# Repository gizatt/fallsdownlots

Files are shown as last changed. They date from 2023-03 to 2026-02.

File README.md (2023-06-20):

# FallsDownLots

<details>
  <summary>Click to expand more demo GIFs</summary>
  
  
  
</details>

## About
This project ("FallsDownLots") is a 2-wheeled balancing robot designed around two brushless DC (BLDC) gimbal motors, controlled with field-oriented control. Previous iterations of wheeled balancing robots I've built have been plagued by issues with poor motor control (primarily backlash, inertia, and friction causing shaky control around the upright fixed point). This project instead uses a high-torque (specifically low KV / high winding count) 3-phase motor, paired with an absolute magnetic encoder to determine the shaft angle, and a 3-phase drive circuit to deliver current. With some pretty simple parts, I've been able to get something pretty close to actual torque control for the wheels of this robot, and it's been pretty easy to tune up for smooth, stable, remote-controllable operation.

For ease of control tuning, I chose a main board with Bluetooth Low-Energy (BLE) support, and written a companion program that connects to the robot and allows parameter updates. This program is currently very primitive but it beats reprogramming or having it drag around a serial cable (which interferes with control).

I mostly rely on [SimpleFOC](https://simplefoc.com/) for the actual FOC implementation, and took their advice on sensor and drive chip choice. I'd like to dive deeper into controlling these motors better -- for example, trying to compensate for cogging torque to get smoother operation - but I have more fundamental issues to fix first (see below).

- For code, see the `fallsdownlots` subdirectory (which is a PlatformIO package).
- For CAD, see [Onshape](https://cad.onshape.com/documents/34e0d9ef519aef4b34c19df6/w/b4fc20d7f51a03280199ecb2/e/801a65f226a9bb9fc692247b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). Sorry it's not organized into a main assembly yet, this is just my 3D print part workshop. Approximately up-to-date STLS are in the `stls` subdirectory. Print `MotorMount` twice, mirroring one of them. Print `Wheel` twice. Print `Tire` twice in TPU or another tacky, flexible filament.
- For PCB design and electrical schematics, see `board_v2` subdirectory (which is a KiCad project).

## Diagram and Parts List
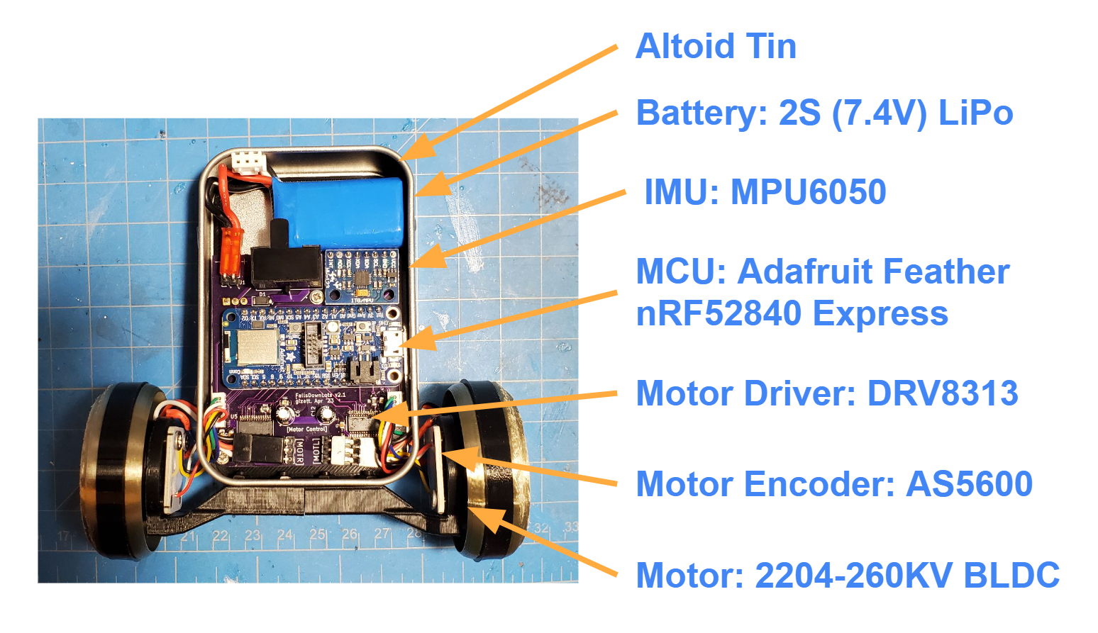
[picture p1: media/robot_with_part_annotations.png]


(Note: this references a special-edition physically packaged version of this robot.)

Parts list:
- 2X PLA wheel with TPU tire
- 2x Motor assembly, composed of...
  - 1x PLA Wheel + TPU tire
  - 1x PLA Motor Mount
  - 1x AS5600 Breakout Board
  - 1X 2204-260KV BLDC Motor (with 3-pin JST RE connector)
  - 1X 10KOhm Thermistor
  - 1X JST MX 6-pin Male Connector
- 1x Altoid tin case with lid, containing...
  - 1x PLA board mounting backplate, already attached to case.
  - 1x Main electronics board
  - 4x M3x8mm hex bolts and nuts
  - 8x M2x4mm hex bolts
  - 3x M2x8mm self-tapping phillips screws
  - Spare parts: M3x8mm self-tapping phillips screws, plus other screw types, plus spare TPU tire

Not included (supply seperately):
- 1x 400Mah 2S LiPO [[Amazon link](https://www.amazon.com/gp/product/B072BH1XP6/ref=ox_sc_act_title_1?smid=A10R5CWYCW5T5E&psc=1)] and balance charger.
- 1.5 and 2.5 metric alley keys
- Small phillips head screwdriver
- Small narrow / needle-nose pliers
- Non-ancient bluetooth adapter (probably needs BLE >= 5.1?)

## Assembly Instructions

Assembly is simple, but the tight packaging makes assembly pretty order-sensitive.

1) Attach the motor assemblies onto the bottom of the case, as shown, using 4x M3x8mm hex bolts and nuts. Before you fully attach these, pass their wires into the case through the nearby holes; otherwise it'll be a tight fit to get those wires passed in, especially with the electronics board mounted. Be reasonably gentle with the wires...


2) Now install the main electronics board by sliding it into place and installing the 3x M2x8mm self-tapping phillips screws, which screw into posts on the PLA backplate. Note that you want the wires from the motor assemblies *over* the main board once it's installed -- it's a bit of dance to get it everything into place.
3) Plug in the wires from the motor assemblies into the plugs on their corresponding side. See picture for exact orientation of wires -- carefully note the orientation of the 3-pin motor connectors! If you get this backwards, the motors will spin the wrong way. I recommend some good needlenose pliers to help with wrangling and attaching these cables.
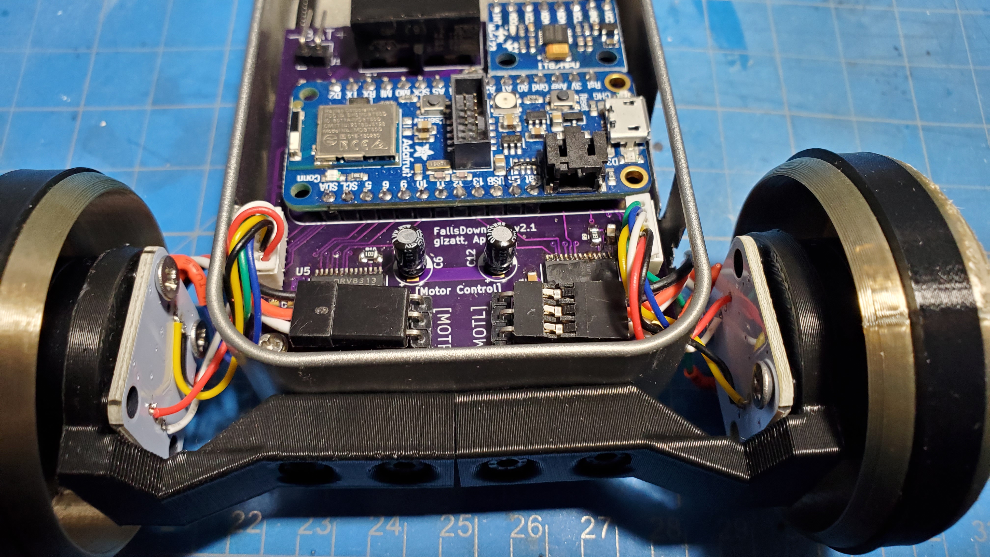
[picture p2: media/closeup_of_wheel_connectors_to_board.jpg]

4) Attach the tires to the motors with at least 2x M2x4mm hex bolts each. These bolts should be snug but don't go ham (the PLA may not be able to take it).
5) Slide the battery into the space under the on-off switch with the cables facing left, and plug in the cable, being careful to have the red wire on the right. *This board technically has reverse bias protection but I have never tested it and I do not want you to either.*

Troubleshooting: contact me!

### Motor assembly internals

I packaged this robot with each motor and sensor already assembled, since their assembly is a bit sensitive, but you're welcome to disassemble and take a look. These assemblies are pancakes of a tiny BLDC motor ([Amazon link](https://www.amazon.com/DAUERHAFT-Brushless-Efficiency-Drones-Gimbal/dp/B08S5JSD3Q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), though this unit is much cheaper on Aliexpress) with a magnet superglued to its shaft, an [absolute magnetic encoder](https://www.amazon.com/Magnetic-Encoder-Induction-Measurement-Precision/dp/B094F8H591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) on a breakout board, and a thermistor sandwiched between them.



## Usage instructions

Flip the switch to the right to turn on. I recommend laying the robot down or standing it on its head during startup; each wheel will independent move a quarter rotation back and forth during startup as a calibration routine (this is managed by SimpleFOC). Once that is done, the robot should be active, and will attempt to balance to the upright if it is within ~60 degrees of upright. The easiest way to get it going is to go to a clear area of floor, holding it sideways, and confidentally and quickly place it roughly upright and let go. The integrators reset and motors turn off again when it is not upright, e.g. if it falls.

I recently discovered another fun demo method that happens to work, despite the control algorithm not being created with this in mind: hold the robot by the wheels, and swing the robot upright. It should catch itself at the upright and stabilize there. See [this video](media/flipup_demo.gif).

Note: there's a few bugs somewhere in the code, especially in the BLE stuff, and sometimes the IMU or magnetic encoders get into weird states and stop talking. If the robot suddenly stops and falls over, or otherwise seems unresponsive, just do a complete power cycle. This is more likely to happen if you're using one of the BLE scripts, proportional to how much data you're sending/receiving.

## Control details

The main control code is implemented in `main-fallsdownlots.cpp::do_control`. I'm currently running a PID loop on angle, with the zero angle estimated via a low-pass filter on the measured angle (which assumes we stabilize on average to the upright), plus a PI loop on wheel velocity, plus a PI loop on yaw velocity. These are all controlled by parameters in the `ControlParams` struct.

There are two Python scripts in the `fallsdownlots/scripts` folder. Both connect to the robot with BLE.
- `communicator.py`: Once connected, type a command of the format "<param name> <float value>" and hit enter, and it'll send it to the robot. It should echo the new setting back, though sometimes it takes a while to come back. If you just send "<param name>" without a value, it'll send the current value back. Example: "ANG_D 0.1" changes the derivative gain to 0.1. Ignore the plot window that opens up, it doesn't work yet...
- `gamepad.py`: Connects to the robot and sends commands (adjusting the setpoints of the velocity and yaw velocity control loops) in response to the arrow keys, letting you control the robot. Hold shift while pressing arrow keys to go faster. There's a mode to display robot odometry (see code) but it's currently super sketchy.

## Notes / Thoughts

### TODOs
- Major code cleanup. Tons of cruft left here I haven't re-orged.
- Use BLE interface to create an interactive motor teststand for tuning up actual motor control loops.

### Stuff that didn't work as well as I hoped
- Because I'm talking to 2 magnetic encoders and 1 IMU over relatively slow I2C (800khz, I think), I haven't been able to get my main control loop to run faster than ~200hz. I'm configuring the IMU to do its own high-rate on-board orientation estimation, so that's fine -- but this low rate makes it hard to drive the motors in anything other than torque mode (velocity and position mode go unstable pretty easily / can't be tuned to be too accurate as my loop rate is probably too low), and I can't crank the actual control gains as high as I'd like for tight tracking without inducing oscillations. It's possible I can get info from at least the magnetic encoders over their analog output instead... but I would need to experiment with that.
- I'm relying on Bluetooth Low-Energy as my wireless comms media, but I'm finding the bandwidth super low, and the code on the embedded side super crash-prone. I'm probably overloading buffers somewhere and configuring stuff wrong... next time, I'm just gonna have the robot connect to my Wifi. I'd rather deal with networking gremlins I sort of understand than BLE ones I don't.

### BLE Comms Protocol

The robot sends a 36-byte (+COBS-encoding) packet over BLE UART at ~30hz consisting of 8 floats:
```
[pitch, yaw, d_pitch, d_yaw, odometry, l_cmd, r_cmd, max_motor_temp]
```

On-board, the robot has a registry of named control parameters that you can write with a command formatted:
```
<NULL-TERMINATED-NAME>[optional single float]
```
and the robot will respond with a similarly formatted message (+COBS-encoding) packet with a single float indicating the updated value, or the current value if you didn't include the float value.

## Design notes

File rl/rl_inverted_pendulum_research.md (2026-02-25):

# RL Controller for Two-Wheeled Inverted Pendulum: Research & Implementation Plan

**Robot:** Altoids tin chassis, two BLDC outrunners, SimpleFOC, magnetic encoder, Arduino Nano 33 BLE (nRF52840), onboard IMU.
**Goal:** Train an RL policy in MuJoCo simulation and deploy it to the Arduino.

---

## Table of Contents

1. [MuJoCo Ecosystem Overview](#1-mujoco-ecosystem-overview)
2. [Framework Comparison: Standalone vs mjlab](#2-framework-comparison-standalone-vs-mjlab)
3. [Recommended Project Structure (Standalone)](#3-recommended-project-structure-standalone)
4. [mjlab-Based Project Structure](#4-mjlab-based-project-structure)
5. [Phase 1: MuJoCo Environment](#5-phase-1-mujoco-environment)
6. [Phase 2: RL Algorithm Choice](#6-phase-2-rl-algorithm-choice)
7. [Phase 3: Training Infrastructure](#7-phase-3-training-infrastructure)
8. [Phase 4: Domain Randomization](#8-phase-4-domain-randomization)
9. [Phase 5: Deploying to Arduino Nano 33 BLE](#9-phase-5-deploying-to-arduino-nano-33-ble)
10. [Implementation Sequence](#10-implementation-sequence)
11. [Sources](#11-sources)

---

## 1. MuJoCo Ecosystem Overview

### MuJoCo Ecosystem Map

| Package | Purpose | Backend | GPU? | Use When |
|---|---|---|---|---|
| `mujoco` | Standard Python bindings | CPU (C) | No | Quick prototyping, CPU-only |
| `mujoco-mjx` | JAX-accelerated MuJoCo | JAX (GPU/TPU) | Yes | Scaling to 1000s of envs (JAX) |
| `mujoco_playground` | Full RL framework on MJX | JAX | Yes | Full locomotion suite (JAX) |
| `mjlab` | Isaac Lab API on MuJoCo Warp | CUDA/Warp | Yes (NVIDIA) | Isaac Lab-style, NVIDIA GPU training |
| `mujoco-py` | Old OpenAI bindings | CPU | No | Deprecated — avoid |

`mjlab` ([github.com/mujocolab/mjlab](https://github.com/mujocolab/mjlab)) adopts Isaac Lab's manager-based composable API and pairs it with MuJoCo Warp (NVIDIA GPU physics). It is **directly analogous** to the Upkie wheeled biped project [mjlab_upkie](https://github.com/MarcDcls/mjlab_upkie), which trains a velocity-tracking and balancing policy for a wheeled biped robot — making it a very close reference for this project.

---

## 2. Framework Comparison: Standalone vs mjlab

### High-Level Tradeoffs

| Dimension | Standalone (`mujoco` + CleanRL) | mjlab |
|---|---|---|
| **GPU requirement** | None (CPU training works fine) | **NVIDIA GPU required** for training |
| **Parallelism** | 8–32 CPU envs (VectorEnv) | 256–4096+ GPU envs (MuJoCo Warp) |
| **Wall-clock training** | ~30–60 min (PPO, 8 envs, 3M steps) | ~5–15 min (2048 envs, same budget) |
| **Algorithm** | PPO, SAC, TD3 (full CleanRL library) | RSL-RL PPO (main); SAC not native |
| **Environment definition** | Python class (`gym.Env`), explicit `step()`/`reset()` | Declarative manager config (`env_cfg.py`), no explicit step |
| **Domain randomization** | Manual code in `_apply_domain_randomization()` | `EventManager` terms, declarative |
| **Logging** | TensorBoard (+ optional W&B) | W&B (primary), TensorBoard possible |
| **Learning curve** | Moderate — gymnasium + CleanRL are well-documented | Steeper — Isaac Lab paradigm (managers, `@configclass`) |
| **Stability** | Stable, mature dependencies | Beta — breaking changes expected |
| **Prior art for this robot** | Generic continuous-control examples | [mjlab_upkie](https://github.com/MarcDcls/mjlab_upkie): wheeled biped, nearly identical task |
| **Weight export to Arduino** | Straightforward (PyTorch → C arrays) | Same (RSL-RL actor is a PyTorch MLP) |

### When to Choose mjlab

Choose mjlab if:
- You have an **NVIDIA GPU** available for training
- You want **10–100x faster iteration** via massive parallelism (critical for domain randomization sweeps)
- You are willing to learn the Isaac Lab manager API (it scales well to more complex tasks)
- You want a ready-made reference: `mjlab_upkie` is almost exactly this project (wheeled biped, velocity control, sim-to-real)

Choose standalone if:
- You are training on **CPU only** (no NVIDIA GPU)
- You want the fastest possible **time-to-first-result** with minimal boilerplate
- You prefer SAC (better sample efficiency on CPU) — mjlab/RSL-RL is PPO-focused
- You want maximum flexibility over reward shaping and observation construction

### Decision Summary

> **If you have an NVIDIA GPU, mjlab is the stronger choice.** The mjlab_upkie reference implementation is a wheeled biped doing exactly what this project needs. Starting from it avoids writing a Gymnasium env from scratch and gets you to 2048 parallel environments immediately. The Isaac Lab config pattern is more verbose but scales better as the task complexity grows.
>
> **If training on CPU, use the standalone approach.** The gymnasium + CleanRL path is simpler, SAC is available, and 8 CPU envs is enough to train a basic balancer in under an hour.

---

## 3. Recommended Project Structure (Standalone)

```
rl/
├── envs/
│   ├── __init__.py              # gym.register() call
│   ├── two_wheel_env.py         # Gymnasium environment
│   └── two_wheel_robot.xml      # MJCF model
├── train_ppo.py                 # Single-file PPO training
├── train_sac.py                 # SAC alternative (copy from CleanRL)
├── export_weights.py            # PyTorch -> C array exporter
├── checkpoints/                 # Saved .pt checkpoints
├── runs/                        # TensorBoard logs
├── videos/                      # Periodic rendered episodes
└── firmware/
    ├── policy_weights.h         # Generated C weight arrays
    └── policy_inference.ino     # Arduino sketch
```

Install dependencies:
```bash
pip install "gymnasium[mujoco]" mujoco torch tensorboard cleanrl
```

---

## 4. mjlab-Based Project Structure

Based directly on [mjlab_upkie](https://github.com/MarcDcls/mjlab_upkie), adapted for a two-wheeled balancer.

```
rl/
├── src/
│   └── two_wheel_mjlab/
│       ├── __init__.py
│       ├── tasks/
│       │   └── balance_env_cfg.py       # Isaac Lab-style manager config
│       └── robot/
│           └── two_wheel/
│               └── two_wheel.xml        # MJCF model (same as standalone)
├── sim.py                               # CPU-side playback via mujoco.viewer
├── export_weights.py                    # RSL-RL checkpoint -> C array
├── pyproject.toml                       # uv/pip metadata
├── logs/                                # RSL-RL checkpoints + W&B artifacts
└── firmware/
    ├── policy_weights.h                 # Generated C weight arrays
    └── policy_inference.ino             # Arduino sketch (same as standalone)
```

Install:
```bash
pip install mjlab rsl-rl wandb
# or: uv add mjlab rsl-rl wandb
```

### 4.1 Environment Configuration (`tasks/balance_env_cfg.py`)

Rather than implementing `step()` and `reset()` by hand, mjlab uses a **declarative manager pattern** — you define *what* the observations, rewards, terminations, and randomization events are; the framework assembles the env loop:

```python
from dataclasses import dataclass, field
import mjlab
from mjlab import ManagerBasedRLEnvCfg, SceneEntityCfg
from mjlab.managers import ObservationsCfg, RewardsCfg, TerminationsCfg, EventCfg, CommandsCfg
import mjlab.managers.observation_terms as obs_terms
import mjlab.managers.reward_terms as rew_terms
import mjlab.managers.event_terms as evt_terms
import mjlab.managers.termination_terms as term_terms

@dataclass
class TwoWheelSceneCfg(SceneEntityCfg):
    num_envs: int = 2048
    dt: float = 0.002
    substeps: int = 5          # 10ms per policy step (100 Hz)
    robot_usd: str = "two_wheel/two_wheel.xml"

@dataclass
class TwoWheelObsCfg(ObservationsCfg):
    # These map to mjlab built-in terms or custom lambdas
    pitch:       obs_terms.ImuRpy      = field(default_factory=lambda: obs_terms.ImuRpy(indices=[1]))
    pitch_rate:  obs_terms.ImuGyro     = field(default_factory=lambda: obs_terms.ImuGyro(indices=[1]))
    roll:        obs_terms.ImuRpy      = field(default_factory=lambda: obs_terms.ImuRpy(indices=[0]))
    roll_rate:   obs_terms.ImuGyro     = field(default_factory=lambda: obs_terms.ImuGyro(indices=[0]))
    left_wheel:  obs_terms.JointVel    = field(default_factory=lambda: obs_terms.JointVel(joint="left_wheel_joint"))
    right_wheel: obs_terms.JointVel    = field(default_factory=lambda: obs_terms.JointVel(joint="right_wheel_joint"))
    base_vel:    obs_terms.BaseLinVel  = field(default_factory=obs_terms.BaseLinVel)
    yaw_rate:    obs_terms.BaseAngVel  = field(default_factory=lambda: obs_terms.BaseAngVel(indices=[2]))

@dataclass
class TwoWheelRewardsCfg(RewardsCfg):
    # Weighted reward terms; mjlab sums them each step
    upright:     rew_terms.UprightPitch     = field(default_factory=lambda: rew_terms.UprightPitch(weight=1.0))
    no_drift:    rew_terms.BaseLinVelPenalty = field(default_factory=lambda: rew_terms.BaseLinVelPenalty(weight=0.1))
    smooth_act:  rew_terms.ActionRatePenalty = field(default_factory=lambda: rew_terms.ActionRatePenalty(weight=0.05))
    no_tilt_vel: rew_terms.PitchRatePenalty  = field(default_factory=lambda: rew_terms.PitchRatePenalty(weight=0.1))

@dataclass
class TwoWheelTerminationsCfg(TerminationsCfg):
    fallen: term_terms.BadOrientation = field(
        default_factory=lambda: term_terms.BadOrientation(limit_pitch=0.5)  # ~28 deg
    )
    timeout: term_terms.TimeOut = field(default_factory=lambda: term_terms.TimeOut(max_episode_steps=1000))

@dataclass
class TwoWheelEventCfg(EventCfg):
    """Domain randomization applied at reset."""
    rand_friction:  evt_terms.RandomizeFriction    = field(default_factory=lambda: evt_terms.RandomizeFriction(scale=(0.6, 1.4)))
    rand_mass:      evt_terms.RandomizeMass        = field(default_factory=lambda: evt_terms.RandomizeMass(scale=(0.8, 1.2)))
    rand_damping:   evt_terms.RandomizeDamping     = field(default_factory=lambda: evt_terms.RandomizeDamping(scale=(0.7, 1.3)))
    rand_motor:     evt_terms.RandomizeActuatorGain = field(default_factory=lambda: evt_terms.RandomizeActuatorGain(scale=(0.8, 1.2)))
    init_tilt:      evt_terms.RandomizeInitPitch   = field(default_factory=lambda: evt_terms.RandomizeInitPitch(range=(-0.08, 0.08)))

@dataclass
class TwoWheelBalanceCfg(ManagerBasedRLEnvCfg):
    scene:        TwoWheelSceneCfg       = field(default_factory=TwoWheelSceneCfg)
    observations: TwoWheelObsCfg         = field(default_factory=TwoWheelObsCfg)
    rewards:      TwoWheelRewardsCfg     = field(default_factory=TwoWheelRewardsCfg)
    terminations: TwoWheelTerminationsCfg = field(default_factory=TwoWheelTerminationsCfg)
    events:       TwoWheelEventCfg       = field(default_factory=TwoWheelEventCfg)
```

> **Note:** The exact manager term names (`obs_terms.ImuRpy`, `rew_terms.UprightPitch`, etc.) depend on mjlab's built-in library, which is still evolving. You may need to define custom terms as lambdas over MuJoCo data. The pattern is identical to Isaac Lab — see mjlab_upkie's `balance_env_cfg.py` for a concrete reference.

### 4.2 Register and Train

```python
# __init__.py
import mjlab
mjlab.register(
    id="TwoWheel-Balance-v0",
    entry_point=TwoWheelBalanceCfg,
)
```

```bash
# Train (NVIDIA GPU required):
uv run train TwoWheel-Balance-v0 --env.scene.num-envs 2048

# Play / evaluate on CPU:
python sim.py --checkpoint logs/rsl_rl/two_wheel_balance/bests/model.pt
```

Training uses **RSL-RL** (on-policy PPO) with automatic W&B logging.

### 4.3 CPU Fallback for Evaluation (`sim.py`)

mjlab_upkie ships a `sim.py` that runs the trained policy against a standard `mujoco.viewer` on CPU — identical to the standalone approach. The weight export and Arduino firmware are also identical since both produce a plain PyTorch MLP.

### 4.4 Key Differences Calling Out

| Topic | Standalone | mjlab |
|---|---|---|
| **Env loop** | Explicit Python (`step`, `reset`, `_get_obs`) | Implicit — framework assembles from manager terms |
| **Domain randomization** | Manual code in `_apply_domain_randomization()` | Declarative `EventCfg` terms at `reset` |
| **Reward shaping** | Python arithmetic in `_compute_reward()` | Weighted `RewardsCfg` terms summed by framework |
| **Observation noise** | Explicit numpy in `_get_obs()` | Noise added as an `ObservationNoiseCfg` term |
| **Scaling** | `num_envs=8` (CPU VectorEnv) | `num_envs=2048` (GPU, ~100x faster) |
| **Algorithm access** | Full CleanRL (PPO, SAC, TD3) | RSL-RL PPO (SAC not natively supported) |
| **Starting point** | From scratch | Fork [mjlab_upkie](https://github.com/MarcDcls/mjlab_upkie) |

### 4.5 mjlab Weight Export (Same as Standalone)

RSL-RL's actor is a standard `torch.nn.Sequential` MLP, so the export script from Section 9 (Option A) works without modification — just point it at the RSL-RL checkpoint instead of a CleanRL checkpoint.

---

## 5. Phase 1: MuJoCo Environment

### 3.1 MJCF Robot Model (`envs/two_wheel_robot.xml`)

```xml
<mujoco model="two_wheel_balancer">
  <compiler angle="radian"/>
  <option gravity="0 0 -9.81" timestep="0.002" integrator="RK4"/>

  <default>
    <joint damping="0.01" armature="0.01"/>
    <geom condim="3" friction="0.8 0.1 0.1"/>
  </default>

  <asset>
    <texture name="grid" type="2d" builtin="checker" rgb1=".1 .2 .3"
             rgb2=".2 .3 .4" width="300" height="300"/>
    <material name="grid" texture="grid" texrepeat="1 1" texuniform="true"/>
  </asset>

  <worldbody>
    <light pos="0 0 1.5" dir="0 0 -1" diffuse="1 1 1"/>
    <geom name="floor" size="0 0 .05" type="plane" material="grid" condim="3"/>

    <!-- Chassis: the "pendulum" body -->
    <body name="chassis" pos="0 0 0.065">
      <!-- freejoint allows unconstrained 3D motion -->
      <!-- For strict 2D: replace with slide(x) + slide(z) + hinge(pitch-Y) -->
      <freejoint name="chassis_free"/>
      <!-- ~80g representing altoids tin + battery + electronics -->
      <geom name="chassis_box" type="box" size="0.03 0.025 0.05"
            mass="0.08" rgba="0.6 0.3 0.1 1"/>
      <site name="imu_site" pos="0 0 0" size="0.005"/>

      <body name="left_wheel" pos="0 -0.04 -0.05">
        <!-- Hinge spins around Y axis -->
        <joint name="left_wheel_joint" type="hinge" axis="0 1 0" damping="0.005"/>
        <geom type="cylinder" size="0.035 0.008" mass="0.02"
              rgba="0.2 0.2 0.8 1" friction="1.0 0.1 0.1"/>
      </body>

      <body name="right_wheel" pos="0 0.04 -0.05">
        <joint name="right_wheel_joint" type="hinge" axis="0 1 0" damping="0.005"/>
        <geom type="cylinder" size="0.035 0.008" mass="0.02"
              rgba="0.2 0.2 0.8 1" friction="1.0 0.1 0.1"/>
      </body>
    </body>
  </worldbody>

  <actuator>
    <!-- gear scales torque; tune to match measured SimpleFOC stall torque (~0.1-0.3 Nm) -->
    <motor name="left_motor"  joint="left_wheel_joint"
           ctrllimited="true" ctrlrange="-1.0 1.0" gear="1"/>
    <motor name="right_motor" joint="right_wheel_joint"
           ctrllimited="true" ctrlrange="-1.0 1.0" gear="1"/>
  </actuator>

  <sensor>
    <gyro      name="imu_gyro"       site="imu_site" noise="0.01"/>
    <framequat name="chassis_quat"   objtype="body" objname="chassis"/>
    <jointvel  name="left_wheel_vel" joint="left_wheel_joint"/>
    <jointvel  name="right_wheel_vel" joint="right_wheel_joint"/>
  </sensor>
</mujoco>
```

**Key modeling decisions:**
- `freejoint` gives full 6-DOF chassis motion (pitch, roll, yaw, xyz translation). This matches the real robot.
- `gear` on the motor actuator is the torque scaling constant. Tune this by measuring max torque output from SimpleFOC.
- Wheel `friction="1.0 0.1 0.1"`: first value is sliding friction (dominant for rolling), second torsional, third rolling resistance.

### 3.2 Gymnasium Environment (`envs/two_wheel_env.py`)

```python
"""
Gymnasium-compatible two-wheeled balancing robot environment.
Wraps MuJoCo via the standard `mujoco` Python bindings.
"""
import os
import numpy as np
import mujoco
import gymnasium as gym
from gymnasium import spaces

class TwoWheelBalancerEnv(gym.Env):
    """
    Observation space (9-dim):
        [0] chassis pitch angle (rad)
        [1] chassis pitch rate (rad/s)
        [2] chassis roll angle (rad)
        [3] chassis roll rate (rad/s)
        [4] left wheel velocity (rad/s)
        [5] right wheel velocity (rad/s)
        [6] x velocity (m/s)
        [7] y velocity (m/s)
        [8] yaw rate (rad/s)

    Action space (2-dim):
        [0] left motor torque  in [-1, 1]
        [1] right motor torque in [-1, 1]
    """

    metadata = {"render_modes": ["human", "rgb_array"], "render_fps": 50}

    def __init__(self, render_mode=None, xml_path=None, domain_randomize=True):
        super().__init__()

        if xml_path is None:
            xml_path = os.path.join(os.path.dirname(__file__), "two_wheel_robot.xml")

        self.model = mujoco.MjModel.from_xml_path(xml_path)
        self.data  = mujoco.MjData(self.model)
        self.domain_randomize = domain_randomize

        # Store nominal model parameters for domain randomization
        self._nominal_geom_friction  = self.model.geom_friction.copy()
        self._nominal_body_mass      = self.model.body_mass.copy()
        self._nominal_dof_damping    = self.model.dof_damping.copy()
        self._nominal_actuator_gear  = self.model.actuator_gear[:, 0].copy()

        self.dt           = self.model.opt.timestep  # 0.002 s
        self.frame_skip   = 5                         # -> 10ms per env step (100 Hz)
        self.max_episode_steps = 1000                 # 10 seconds

        obs_high = np.array([
            np.pi, 20.0, np.pi, 20.0,   # pitch, pitch_rate, roll, roll_rate
            50.0, 50.0,                  # wheel velocities
            3.0, 3.0, 10.0,             # x_vel, y_vel, yaw_rate
        ], dtype=np.float32)

        self.observation_space = spaces.Box(low=-obs_high, high=obs_high, dtype=np.float32)
        self.action_space = spaces.Box(low=-1.0, high=1.0, shape=(2,), dtype=np.float32)

        self._step_count = 0
        self._renderer = None
        self.render_mode = render_mode

    # ------------------------------------------------------------------
    # Gymnasium API
    # ------------------------------------------------------------------

    def reset(self, seed=None, options=None):
        super().reset(seed=seed)
        mujoco.mj_resetData(self.model, self.data)

        if self.domain_randomize:
            self._apply_domain_randomization()

        # Small random initial tilt: ±5 degrees
        pitch_init = self.np_random.uniform(-0.08, 0.08)
        # chassis_free joint: qpos[0:3]=xyz, qpos[3:7]=quaternion [w,x,y,z]
        half = pitch_init / 2.0
        self.data.qpos[3] = np.cos(half)  # w
        self.data.qpos[4] = 0.0            # x
        self.data.qpos[5] = np.sin(half)   # y (pitch axis)
        self.data.qpos[6] = 0.0            # z

        self._step_count = 0
        mujoco.mj_forward(self.model, self.data)
        return self._get_obs(), {}

    def step(self, action):
        action = np.clip(action, -1.0, 1.0).astype(np.float64)
        self.data.ctrl[:] = action

        for _ in range(self.frame_skip):
            mujoco.mj_step(self.model, self.data)

        obs = self._get_obs()
        reward = self._compute_reward(obs, action)

        pitch = obs[0]
        terminated = bool(abs(pitch) > 0.5)  # ~28 degrees -> fallen
        self._step_count += 1
        truncated = self._step_count >= self.max_episode_steps

        if self.render_mode == "human":
            self.render()

        return obs, reward, terminated, truncated, {}

    def render(self):
        if self._renderer is None:
            self._renderer = mujoco.Renderer(self.model, height=480, width=640)
        self._renderer.update_scene(self.data)
        if self.render_mode == "rgb_array":
            return self._renderer.render()

    def close(self):
        if self._renderer is not None:
            self._renderer.close()

    # ------------------------------------------------------------------
    # Internal helpers
    # ------------------------------------------------------------------

    def _get_obs(self):
        # chassis_free joint: qpos[0:3]=xyz, qpos[3:7]=quat(w,x,y,z)
        #                     qvel[0:3]=xyz_vel, qvel[3:6]=angular_vel
        quat = self.data.qpos[3:7]
        pitch, roll = _quat_to_pitch_roll(quat)

        pitch_rate = self.data.qvel[4]  # angular vel around Y (pitch axis)
        roll_rate  = self.data.qvel[3]  # angular vel around X (roll axis)
        yaw_rate   = self.data.qvel[5]  # angular vel around Z (yaw axis)
        x_vel      = self.data.qvel[0]
        y_vel      = self.data.qvel[1]

        # Wheel joints follow freejoint: qvel indices 6 and 7
        lw_vel = self.data.qvel[6]
        rw_vel = self.data.qvel[7]

        obs = np.array([
            pitch, pitch_rate, roll, roll_rate,
            lw_vel, rw_vel,
            x_vel, y_vel, yaw_rate,
        ], dtype=np.float32)

        # Add IMU-like sensor noise
        obs[0] += self.np_random.normal(0, 0.01)   # pitch noise  (~0.5 deg)
        obs[1] += self.np_random.normal(0, 0.05)   # pitch rate noise
        obs[2] += self.np_random.normal(0, 0.01)   # roll noise
        obs[3] += self.np_random.normal(0, 0.05)   # roll rate noise

        return obs

    def _compute_reward(self, obs, action):
        pitch, pitch_rate = obs[0], obs[1]
        x_vel, y_vel      = obs[6], obs[7]

        r_upright  =  1.0 - 2.0 * (pitch**2)       # reward for staying upright
        r_still    = -0.1 * (x_vel**2 + y_vel**2)  # penalize drifting
        r_smooth   = -0.05 * np.sum(action**2)       # penalize torque spikes
        r_tilt_vel = -0.1 * (pitch_rate**2)          # penalize rapid tilting

        return float(r_upright + r_still + r_smooth + r_tilt_vel)

    def _apply_domain_randomization(self):
        rng = self.np_random

        # Friction: ±40%
        self.model.geom_friction[:] = self._nominal_geom_friction * rng.uniform(0.6, 1.4)

        # Body masses: ±20% per body
        self.model.body_mass[:] = (
            self._nominal_body_mass * rng.uniform(0.8, 1.2, size=self._nominal_body_mass.shape)
        )

        # Joint damping: ±30%
        self.model.dof_damping[:] = (
            self._nominal_dof_damping * rng.uniform(0.7, 1.3, size=self._nominal_dof_damping.shape)
        )

        # Motor torque gain: ±20%
        self.model.actuator_gear[:, 0] = self._nominal_actuator_gear * rng.uniform(0.8, 1.2)

        # Recompute derived quantities after changing mass/inertia
        mujoco.mj_setConst(self.model, self.data)

def _quat_to_pitch_roll(q):
    """Extract pitch (around Y) and roll (around X) from quaternion [w, x, y, z]."""
    w, x, y, z = q
    sinp = np.clip(2.0 * (w * y - z * x), -1.0, 1.0)
    pitch = np.arcsin(sinp)
    sinr_cosp = 2.0 * (w * x + y * z)
    cosr_cosp = 1.0 - 2.0 * (x * x + y * y)
    roll = np.arctan2(sinr_cosp, cosr_cosp)
    return pitch, roll
```

Register the environment (`envs/__init__.py`):
```python
import gymnasium as gym
gym.register(
    id="TwoWheelBalancer-v0",
    entry_point="envs.two_wheel_env:TwoWheelBalancerEnv",
    max_episode_steps=1000,
)
```

---

## 6. Phase 2: RL Algorithm Choice

### Comparison Table

| Property | PPO | SAC | TD3 |
|---|---|---|---|
| Type | On-policy | Off-policy | Off-policy |
| Sample efficiency | Low | **High** | Moderate-High |
| Replay buffer | No | Yes (~1M steps) | Yes (~1M steps) |
| Policy type | Stochastic | Stochastic (entropy-max) | Deterministic |
| Exploration | Policy std | Automatic entropy tuning | Manual Gaussian noise |
| Hyperparameter sensitivity | Low | **Low (auto-alpha)** | Moderate |
| Stability | **Very stable** | Very stable | Stable |
| Steps to solve balancing | ~1–5M | ~200–500k | ~500k–1M |
| Beginner-friendly | **Highest** | High | Moderate |

### Recommendation

1. **Start with PPO** — validate that the environment is correct and produces sensible behavior. No replay buffer complexity, very stable.
2. **Switch to SAC** — once PPO works, SAC converges 5–10x faster and handles continuous control very well. The automatic entropy (`log_alpha`) tuning removes manual exploration noise tuning.

**Use [CleanRL](https://github.com/vwxyzjn/cleanrl)** as the base. Their `ppo_continuous_action.py` and `sac_continuous_action.py` are ~400 lines each, single-file, and production-quality. Adapt them to your environment rather than writing from scratch.

### Network Architecture

A small MLP is sufficient and advantageous for deployment:

```
Actor:  obs(9) -> Linear(64) -> Tanh -> Linear(64) -> Tanh -> Linear(2) -> Tanh
Critic: obs(9) -> Linear(64) -> Tanh -> Linear(64) -> Tanh -> Linear(1)
```

Using `Tanh` activations (as in CleanRL's orthogonal-init setup) works well. The 9→64→64→2 actor has only ~4,930 parameters — trivially small for deployment.

---

## 7. Phase 3: Training Infrastructure

### Key Script Features

All features should live in a single training file (modeled on CleanRL):

```python
@dataclasses.dataclass
class Args:
    exp_name:        str   = "two_wheel_ppo"
    seed:            int   = 1
    total_timesteps: int   = 3_000_000
    num_envs:        int   = 8          # parallel environments
    num_steps:       int   = 2048       # rollout length per env
    learning_rate:   float = 3e-4
    # ... PPO hyperparameters ...
    track_wandb:     bool  = False
    save_interval:   int   = 100        # checkpoint every N updates
    render_interval: int   = 200        # record video every N updates
    resume_path: Optional[str] = None
```

### Checkpointing

```python
def save_checkpoint(update, path):
    torch.save({
        "update": update,
        "model_state_dict": agent.state_dict(),
        "optimizer_state_dict": optimizer.state_dict(),
    }, path)

def load_checkpoint(path):
    ckpt = torch.load(path, map_location=device)
    agent.load_state_dict(ckpt["model_state_dict"])
    optimizer.load_state_dict(ckpt["optimizer_state_dict"])
    return ckpt["update"] + 1  # start_update
```

**Resume usage:**
```bash
python train_ppo.py                                                     # first run
python train_ppo.py --resume_path checkpoints/.../update_100.pt        # resume
```

### TensorBoard Logging

```python
writer = SummaryWriter(f"runs/{run_name}")
# Log per-update:
writer.add_scalar("losses/policy_loss", pg_loss.item(), global_step)
writer.add_scalar("losses/value_loss",  v_loss.item(),  global_step)
writer.add_scalar("losses/entropy",     ent_loss.item(), global_step)
# Log per-episode (from gymnasium RecordEpisodeStatistics wrapper):
writer.add_scalar("charts/episodic_return", ep_ret, global_step)
writer.add_scalar("charts/episodic_length", ep_len, global_step)
```

```bash
tensorboard --logdir runs/
```

### Periodic Policy Visualization

```python
from gymnasium.wrappers import RecordVideo

if update % args.render_interval == 0:
    render_env = gym.make(args.env_id, render_mode="rgb_array")
    render_env = RecordVideo(
        render_env,
        video_folder=f"videos/{run_name}",
        episode_trigger=lambda ep: True,
        name_prefix=f"update_{update}",
    )
    obs, _ = render_env.reset()
    done = False
    while not done:
        with torch.no_grad():
            action, *_ = agent.get_action_and_value(
                torch.tensor(obs).unsqueeze(0).to(device)
            )
        obs, _, terminated, truncated, _ = render_env.step(
            action.cpu().numpy().squeeze()
        )
        done = terminated or truncated
    render_env.close()
```

### Optional W&B Integration

```python
if args.track_wandb:
    import wandb
    wandb.init(project=args.wandb_project, name=run_name,
               config=dataclasses.asdict(args), sync_tensorboard=True)
```

---

## 8. Phase 4: Domain Randomization

Domain randomization is the primary tool for sim-to-real transfer. Apply it at every `reset()`.

### Parameters and Ranges

| Parameter | MuJoCo Field | Range | Rationale |
|---|---|---|---|
| Wheel/floor friction | `model.geom_friction` | ±40% of nominal | Wheel slip on different surfaces |
| Body masses | `model.body_mass` | ±20% per body | Battery level changes CoM |
| Joint damping | `model.dof_damping` | ±30% | BLDC cogging, back-EMF variation |
| Motor torque gain | `model.actuator_gear` | ±20% | SimpleFOC current loop calibration error |
| IMU angle noise | Added in `_get_obs()` | σ = 0.01 rad | nRF52840 IMU noise floor |
| IMU rate noise | Added in `_get_obs()` | σ = 0.05 rad/s | Gyro noise |
| **Action latency** | Ring buffer in `step()` | 1–3 steps (10–30ms) | BLE + compute delay — often the most critical |
| CoM offset | `model.body_ipos` | ±5mm | Uneven weight distribution |

**Critical:** After changing mass/inertia fields, always call:
```python
mujoco.mj_setConst(self.model, self.data)
```

### Action Latency Buffer

This is often the most impactful randomization for real hardware:

```python
def __init__(self, ...):
    self._action_delay_steps = 2        # nominal 2 steps * 10ms = 20ms
    self._action_buffer = np.zeros((5, 2))  # ring buffer

def step(self, action):
    delay = self.np_random.integers(1, self._action_delay_steps + 1)
    self._action_buffer = np.roll(self._action_buffer, 1, axis=0)
    self._action_buffer[0] = action
    delayed_action = self._action_buffer[delay]
    self.data.ctrl[:] = np.clip(delayed_action, -1.0, 1.0)
    # ... rest of step
```

### Curriculum Schedule

Start training **without randomization** until the policy reliably balances, then linearly increase randomization ranges:

```python
def get_randomization_scale(update, total_updates):
    """Ramp from 10% to 100% of nominal randomization ranges over first half of training."""
    return min(1.0, 0.1 + 0.9 * (2.0 * update / total_updates))
```

---

## 9. Phase 5: Deploying to Arduino Nano 33 BLE

### Hardware Budget (nRF52840: 1MB Flash, 256KB RAM, Cortex-M4 @ 64MHz)

For a 3-layer MLP with architecture 9 → 64 → 64 → 2:

| Representation | Parameters | Flash | Inference RAM |
|---|---|---|---|
| float32 | 4,930 | ~20 KB | 512 bytes |
| int8 quantized | 4,930 | ~5 KB | 128 bytes |

Both are trivially small. No network compression needed.

### Option A: Manual C++ Inference (Recommended First)

No library dependencies. Zero overhead. Validate numerical match with Python before moving to TFLite.

**Export script (`export_weights.py`):**
```python
import torch
import numpy as np

def tensor_to_c_array(t, name):
    arr = t.detach().cpu().numpy()
    shape_str = "][".join(str(d) for d in arr.shape)
    vals = ", ".join(f"{v:.8f}f" for v in arr.flatten())
    return f"static const float {name}[{shape_str}] = {{{vals}}};\n"

# Load trained agent
agent = torch.load("models/final.pt", map_location="cpu")
# actor_mean is Sequential([Linear, Tanh, Linear, Tanh, Linear])
layers = [l for l in agent.actor_mean if isinstance(l, torch.nn.Linear)]

with open("firmware/policy_weights.h", "w") as f:
    f.write("#pragma once\n\n")
    for i, layer in enumerate(layers, start=1):
        f.write(tensor_to_c_array(layer.weight, f"W{i}"))
        f.write(tensor_to_c_array(layer.bias,   f"b{i}"))

print("Exported firmware/policy_weights.h")
```

**C++ inference (`firmware/policy.h`):**
```cpp
#pragma once
#include <math.h>
#include "policy_weights.h"  // generated by export_weights.py

// Network: 9 -> 64 -> 64 -> 2, activations: Tanh, Tanh, Tanh
void policy_forward(const float obs[9], float action[2]) {
    float h1[64], h2[64];

    // Layer 1: h1 = tanh(W1 @ obs + b1)
    for (int i = 0; i < 64; i++) {
        float sum = b1[i];
        for (int j = 0; j < 9; j++) sum += W1[i][j] * obs[j];
        h1[i] = tanhf(sum);
    }

    // Layer 2: h2 = tanh(W2 @ h1 + b2)
    for (int i = 0; i < 64; i++) {
        float sum = b2[i];
        for (int j = 0; j < 64; j++) sum += W2[i][j] * h1[j];
        h2[i] = tanhf(sum);
    }

    // Output: action = tanh(W3 @ h2 + b3), squashed to [-1, 1]
    for (int i = 0; i < 2; i++) {
        float sum = b3[i];
        for (int j = 0; j < 64; j++) sum += W3[i][j] * h2[j];
        action[i] = tanhf(sum);
    }
}
```

**Arduino sketch (`firmware/policy_inference.ino`):**
```cpp
#include "policy.h"
// ... IMU and SimpleFOC setup ...

void loop() {
    // Populate observation from IMU and wheel encoders
    float obs[9];
    obs[0] = imu.getPitch();        // rad
    obs[1] = imu.getPitchRate();    // rad/s
    obs[2] = imu.getRoll();         // rad
    obs[3] = imu.getRollRate();     // rad/s
    obs[4] = motor_left.shaft_velocity;   // rad/s
    obs[5] = motor_right.shaft_velocity;  // rad/s
    obs[6] = 0.0f;  // x_vel: not directly measured; can estimate from wheel avg
    obs[7] = 0.0f;  // y_vel: not measured
    obs[8] = imu.getYawRate();      // rad/s

    // Run policy
    float action[2];
    policy_forward(obs, action);

    // action is in [-1, 1]; scale to motor torque command
    motor_left.move(action[0]  * MAX_TORQUE_NM);
    motor_right.move(action[1] * MAX_TORQUE_NM);

    delayMicroseconds(10000);  // 100 Hz control loop
}
```

### Option B: TFLite Micro (Better for Long-Term Maintainability)

Use if you want int8 quantization benefits or the CMSIS-NN backend (accelerated int8 matmuls on Cortex-M4 DSP).

**Export pipeline (PyTorch → ONNX → TFLite int8):**
```python
# Step 1: Export to ONNX
import torch
dummy = torch.zeros(1, 9)
torch.onnx.export(agent.actor_mean, dummy, "policy.onnx",
                  input_names=["obs"], output_names=["action"],
                  opset_version=13)

# Step 2: ONNX -> TFLite with int8 quantization
# pip install onnx2tf
import onnx2tf
onnx2tf.convert(
    input_onnx_file_path="policy.onnx",
    output_folder_path="tflite_model",
    quant_type="full_int8",
)

# Step 3: Convert to C array
# xxd -i tflite_model/policy_full_int8.tflite > firmware/policy_model_data.h
```

Arduino sketch uses `Arduino_TensorFlowLite` library (or the maintained `Chirale_TensorFlowLite` fork):
```cpp
#include <TensorFlowLite.h>
#include "policy_model_data.h"

constexpr int kTensorArenaSize = 20 * 1024;
alignas(16) uint8_t tensor_arena[kTensorArenaSize];
// ... standard TFLite Micro setup + invoke pattern ...
```

### Observation Normalization (Critical)

Observations in simulation may not be on the same scale as real sensor outputs. Add normalization in the training script and match it exactly on the Arduino:

```python
# Training: normalize observations before feeding to network
obs_mean = np.array([0., 0., 0., 0., 0., 0., 0., 0., 0.])  # update from data
obs_std  = np.array([0.3, 2.0, 0.3, 2.0, 10.0, 10.0, 1.0, 1.0, 2.0])
normalized_obs = (obs - obs_mean) / obs_std
```

```cpp
// Arduino: same normalization
static const float OBS_MEAN[9] = {0., 0., 0., 0., 0., 0., 0., 0., 0.};
static const float OBS_STD[9]  = {0.3, 2.0, 0.3, 2.0, 10.0, 10.0, 1.0, 1.0, 2.0};
for (int i = 0; i < 9; i++) obs[i] = (obs[i] - OBS_MEAN[i]) / OBS_STD[i];
```

---

## 10. Implementation Sequence

### Step-by-Step Plan

**Step 1: Environment validation**
- Implement MJCF + Gymnasium env, disabled domain randomization
- Verify simulation is stable with zero actions (robot should fall naturally)
- Verify it falls within expected timeframe (~1s)
- Use `mujoco.viewer.launch_passive()` to visually inspect the model

**Step 2: PPO baseline (no domain randomization)**
- Copy CleanRL `ppo_continuous_action.py`, adapt for `TwoWheelBalancer-v0`
- Add checkpointing and periodic video
- Train to convergence (~1–5M steps, ~30min on a modern CPU with 8 envs)
- Inspect reward curves for sign of learning

**Step 3: Domain randomization**
- Enable randomization one parameter at a time
- Verify policy still converges with each addition
- Start with ±10% ranges, then expand to the full ranges above
- Action latency is usually the hardest — add last

**Step 4: Switch to SAC for efficiency**
- Copy CleanRL `sac_continuous_action.py`
- Expect ~5x faster convergence
- Compare final performance against PPO

**Step 5: Weight export and C++ validation**
- Run `export_weights.py` to generate `policy_weights.h`
- Write a Python script that runs both the PyTorch model and the manual C++ inference (compiled via `cffi` or just test in a separate C program)
- Assert numerical agreement to within 1e-5

**Step 6: Hardware deployment**
- Flash firmware to Nano 33 BLE
- Log real robot observations during PID operation; compare distributions to simulation
- Tune `MAX_TORQUE_NM` scaling
- Enable the RL policy; expect to iterate on observation normalization and action scaling

### Key Gotchas

| Issue | Solution |
|---|---|
| Policy learned in sim doesn't transfer | Check obs normalization, action scaling, and latency modeling |
| IMU pitch convention mismatch | Log raw IMU values during PID op; verify sign conventions match MJCF |
| Action latency causes instability | Model 1–3 step delay in sim; add `delayMicroseconds` between sense and act |
| Reward function too sparse | Use the shaped reward above; avoid sparse ±1 rewards |
| Policy exploits sim artifacts | Add more aggressive domain randomization; randomize gravity slightly |

---

## 11. Sources

- [MuJoCo XML Reference](https://mujoco.readthedocs.io/en/stable/XMLreference.html)
- [MuJoCo Modeling Documentation](https://mujoco.readthedocs.io/en/stable/modeling.html)
- [Gymnasium MuJoCo Environments](https://gymnasium.farama.org/environments/mujoco/)
- [CleanRL GitHub](https://github.com/vwxyzjn/cleanrl)
- [CleanRL PPO Continuous Action](https://github.com/vwxyzjn/cleanrl/blob/master/cleanrl/ppo_continuous_action.py)
- [CleanRL SAC Continuous Action](https://github.com/vwxyzjn/cleanrl/blob/master/cleanrl/sac_continuous_action.py)
- [CleanRL Resume Training Docs](https://docs.cleanrl.dev/advanced/resume-training/)
- [PPO vs SAC vs TD3 for locomotion tasks](https://www.scirp.org/journal/paperinformation?paperid=131938)
- [LiteRT (TFLite) for Microcontrollers](https://ai.google.dev/edge/litert/microcontrollers/overview)
- [TFLite Micro on Arduino Nano 33 BLE](https://forum.arduino.cc/t/tensorflow-lite-where-is-the-model-during-runtime-in-arduino-nano-33-ble-ram-or-flash/850823)
- [CMSIS-NN accelerated inference on ARM Cortex-M](https://blog.tensorflow.org/2021/02/accelerated-inference-on-arm-microcontrollers-with-tensorflow-lite.html)
- [mjlab PyPI](https://pypi.org/project/mjlab/)
- [mjlab GitHub](https://github.com/mujocolab/mjlab)
- [mjlab_upkie: wheeled biped RL on mjlab (close reference)](https://github.com/MarcDcls/mjlab_upkie)
- [RSL-RL (on-policy PPO used by mjlab)](https://github.com/leggedrobotics/rsl_rl)
- [MuJoCo Playground (MJX + JAX RL framework)](https://github.com/google-deepmind/mujoco_playground)
- [MuJoCo XLA (MJX) Documentation](https://mujoco.readthedocs.io/en/stable/mjx.html)
- [MuJoCo Menagerie (reference robot models)](https://github.com/google-deepmind/mujoco_menagerie)

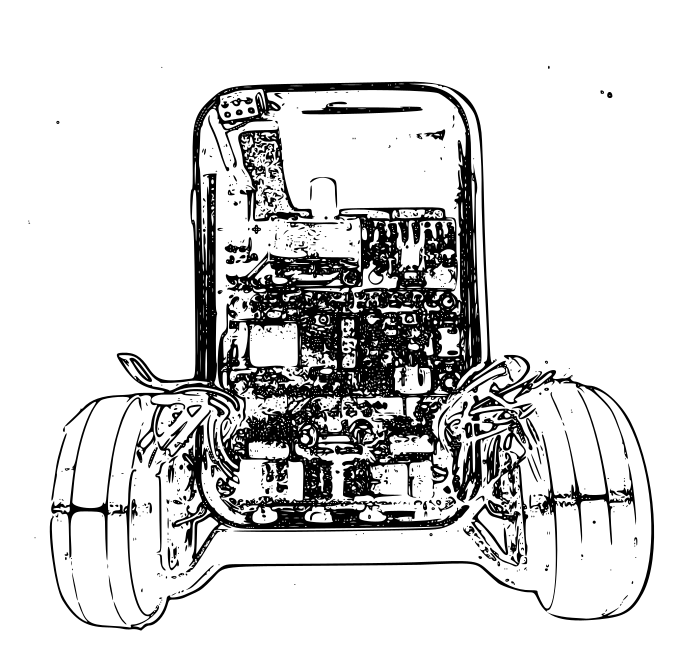
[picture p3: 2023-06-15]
media/robot_linedrawing.png

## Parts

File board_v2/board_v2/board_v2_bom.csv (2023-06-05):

Source: | C:\Users\Greg Izatt\src\fallsdownlots\board_v2\board_v2\board_v2.kicad_sch
Date: | 6/4/2023 8:46:51 PM
Tool: | Eeschema 7.0.1
Generator: | C:\Program Files\KiCad\7.0\bin\scripting\plugins/bom_csv_grouped_by_value.py
Component Count: | 35
Collated Components:
Item | Qty | Reference(s) | Value | LibPart | Footprint | Datasheet | DNP
1 | 1 | A1 | Adafruit_Feather_M0_Express | MCU_Module:Adafruit_Feather_Generic | Module:Adafruit_Feather | https://cdn-learn.adafruit.com/downloads/pdf/adafruit-feather.pdf
2 | 2 | C1, C7 | .01uF | Device:C | Capacitor_SMD:C_0805_2012Metric_Pad1.18x1.45mm_HandSolder | ~
3 | 4 | C2, C3, C8, C9 | .1uF | Device:C_Small | Capacitor_SMD:C_0805_2012Metric_Pad1.18x1.45mm_HandSolder | ~
4 | 3 | C4, C10, C13 | .1uF | Device:C | Capacitor_SMD:C_0805_2012Metric_Pad1.18x1.45mm_HandSolder | ~
5 | 2 | C5, C11 | .47uF | Device:C_Small | Capacitor_SMD:C_0805_2012Metric_Pad1.18x1.45mm_HandSolder | ~
6 | 2 | C6, C12 | 10uF | Device:C_Polarized | Capacitor_THT:CP_Radial_D5.0mm_P2.50mm | ~
7 | 1 | D1 | DSchottky | Device:D_Schottky | Diode_SMD:D_SOD-128 | ~
8 | 1 | J1 | Battery | Connector:Conn_01x02_Male | Connector_PinHeader_2.54mm:PinHeader_1x02_P2.54mm_Horizontal | ~
9 | 1 | J2 | MOTR_SENS | Connector:Conn_01x06_Female | Connector:JST MX x6 | ~
10 | 1 | J3 | MOTL_SENS | Connector:Conn_01x06_Female | Connector:JST MX x6 | ~
11 | 1 | J4 | MOTL | Connector:Conn_01x03_Male | Connector_PinHeader_2.54mm:PinHeader_1x03_P2.54mm_Horizontal | ~
12 | 1 | J6 | MOTR | Connector:Conn_01x03_Male | Connector_PinHeader_2.54mm:PinHeader_1x03_P2.54mm_Horizontal | ~
13 | 2 | R1, R2 | R1K | Device:R | Resistor_SMD:R_0805_2012Metric_Pad1.20x1.40mm_HandSolder | ~
14 | 1 | R3 | 1M | Device:R | Resistor_SMD:R_0805_2012Metric_Pad1.20x1.40mm_HandSolder | ~
15 | 1 | R4 | 470K | Device:R | Resistor_SMD:R_0805_2012Metric_Pad1.20x1.40mm_HandSolder | ~
16 | 6 | R5, R6, R7, R8, R9, R10 | R10K | Device:R | Resistor_SMD:R_0805_2012Metric_Pad1.20x1.40mm_HandSolder | ~
17 | 1 | SW1 | SW_SPDT | Switch:SW_SPDT | downloaded:SW_L102021ML04Q | ~
18 | 1 | U1 | LD33V | ld33v:LD33V | Package_TO_SOT_THT:TO-220-3_Horizontal_TabDown
19 | 1 | U2 | MPU-6050-Breakout | Sensor_Motion:MPU-6050-Breakout | Sensor_Motion:MPU6050_Breakout_8pin_2.54mm
20 | 2 | U3, U5 | DRV8313PWP | DRV8313PWP:DRV8313PWP | downloaded:IC_TPS61196PWPRQ1

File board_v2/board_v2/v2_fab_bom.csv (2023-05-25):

Id | Designator | Footprint | Quantity | Designation | Supplier and ref
1 | C5,C11 | C_0805_2012Metric_Pad1.18x1.45mm_HandSolder | 2 | .47uF |  | check
2 | C12,C6 | CP_Radial_D5.0mm_P2.50mm | 2 | 10uF |  | check
3 | C9,C2,C3,C10,C8,C13,C4 | C_0805_2012Metric_Pad1.18x1.45mm_HandSolder | 7 | .1uF |  | check
4 | J2 | JST MX x6 | 1 | MOTR_SENS |  | check
5 | R1,R2 | R_0805_2012Metric_Pad1.20x1.40mm_HandSolder | 2 | R1K |  | check
6 | U2 | MPU6050_Breakout_8pin_2.54mm | 1 | MPU-6050-Breakout |  | check
7 | J1 | PinHeader_1x02_P2.54mm_Horizontal | 1 | Battery |  | check
8 | J4 | PinHeader_1x03_P2.54mm_Horizontal | 1 | MOTL |  | check
9 | J3 | JST MX x6 | 1 | MOTL_SENS |  | check
10 | U5,U3 | IC_TPS61196PWPRQ1 | 2 | DRV8313PWP |  | check
11 | C7,C1 | C_0805_2012Metric_Pad1.18x1.45mm_HandSolder | 2 | .01uF |  | check
12 | R3 | R_0805_2012Metric_Pad1.20x1.40mm_HandSolder | 1 | 1M |  | check
13 | J6 | PinHeader_1x03_P2.54mm_Horizontal | 1 | MOTR |  | check
14 | SW1 | SW_L102021ML04Q | 1 | SW_SPDT |  | check
15 | D1 | D_SOD-128 | 1 | DSchottky |  | check
16 | R4 | R_0805_2012Metric_Pad1.20x1.40mm_HandSolder | 1 | 500K |  | 470K instead, check
17 | R5,R6 | R_0805_2012Metric_Pad1.20x1.40mm_HandSolder | 2 | R10K |  | check
18 | A1 | Adafruit_Feather_M0_Wifi_WithMountingHoles | 1 | Adafruit_Feather_M0_Express |  | check
19 | U1 | TO-220-3_Horizontal_TabDown | 1 | LD33V |  | check

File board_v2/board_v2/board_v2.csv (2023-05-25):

Source: | C:\Users\Greg Izatt\src\fallsdownlots\board_v2\board_v2\board_v2.kicad_sch
Date: | 4/17/2023 2:16:00 PM
Tool: | Eeschema 7.0.1
Generator: | C:\Program Files\KiCad\7.0\bin\scripting\plugins/bom_csv_grouped_by_value_with_fp.py
Component Count: | 31
Ref | Qnty | Value | Cmp name | Footprint | Description | Vendor | DNP
A1 | 1 | Adafruit_Feather_M0_Express | Adafruit_Feather_M0_Express | Module:Adafruit_Feather_M0_Wifi_WithMountingHoles | Microcontroller module with SAMD21 Cortex-M0 MCU and SPI Flash
C1, C7 | 2 | .01uF | C | Capacitor_SMD:C_0805_2012Metric_Pad1.18x1.45mm_HandSolder | Unpolarized capacitor
C2, C3, C4, C8, C9, C10, C13 | 7 | .1uF | C | Capacitor_SMD:C_0805_2012Metric_Pad1.18x1.45mm_HandSolder | Unpolarized capacitor
C5, C11 | 2 | .47uF | C_Small | Capacitor_SMD:C_0805_2012Metric_Pad1.18x1.45mm_HandSolder | Unpolarized capacitor, small symbol
C6, C12 | 2 | 10uF | C_Polarized | Capacitor_THT:CP_Radial_D5.0mm_P2.50mm | Polarized capacitor
D1 | 1 | DSchottky | D_Schottky | Diode_SMD:D_SOD-128 | Schottky diode
J1 | 1 | Battery | Conn_01x02_Male | Connector_PinHeader_2.54mm:PinHeader_1x02_P2.54mm_Horizontal | Generic connector, single row, 01x02, script generated (kicad-library-utils/schlib/autogen/connector/)
J2 | 1 | MOTR_SENS | Conn_01x06_Female | Connector:JST MX x6 | Generic connector, single row, 01x06, script generated (kicad-library-utils/schlib/autogen/connector/)
J3 | 1 | MOTL_SENS | Conn_01x06_Female | Connector:JST MX x6 | Generic connector, single row, 01x06, script generated (kicad-library-utils/schlib/autogen/connector/)
J4 | 1 | MOTL | Conn_01x03_Male | Connector_PinHeader_2.54mm:PinHeader_1x03_P2.54mm_Horizontal | Generic connector, single row, 01x03, script generated (kicad-library-utils/schlib/autogen/connector/)
J6 | 1 | MOTR | Conn_01x03_Male | Connector_PinHeader_2.54mm:PinHeader_1x03_P2.54mm_Horizontal | Generic connector, single row, 01x03, script generated (kicad-library-utils/schlib/autogen/connector/)
R1, R2 | 2 | R1K | R | Resistor_SMD:R_0805_2012Metric_Pad1.20x1.40mm_HandSolder | Resistor
R3 | 1 | 1M | R | Resistor_SMD:R_0805_2012Metric_Pad1.20x1.40mm_HandSolder | Resistor
R4 | 1 | 470K | R | Resistor_SMD:R_0805_2012Metric_Pad1.20x1.40mm_HandSolder | Resistor
R5, R6 | 2 | R10K | R | Resistor_SMD:R_0805_2012Metric_Pad1.20x1.40mm_HandSolder | Resistor
SW1 | 1 | SW_SPDT | SW_SPDT | downloaded:SW_L102021ML04Q | Switch, single pole double throw
U1 | 1 | LD33V | LD33V | Package_TO_SOT_THT:TO-220-3_Horizontal_TabDown
U2 | 1 | MPU-6050-Breakout | MPU-6050-Breakout | Sensor_Motion:MPU6050_Breakout_8pin_2.54mm
U3, U5 | 2 | DRV8313PWP | DRV8313PWP | downloaded:IC_TPS61196PWPRQ1

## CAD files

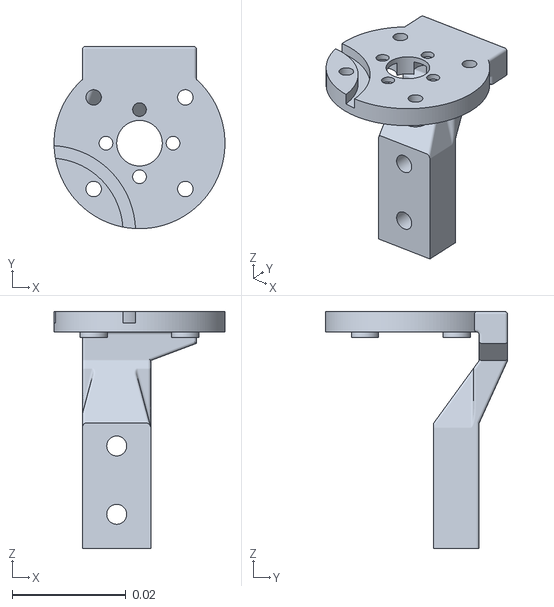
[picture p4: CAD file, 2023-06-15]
stls/MotorMount.stl
0.03 x 0.032 x 0.0416

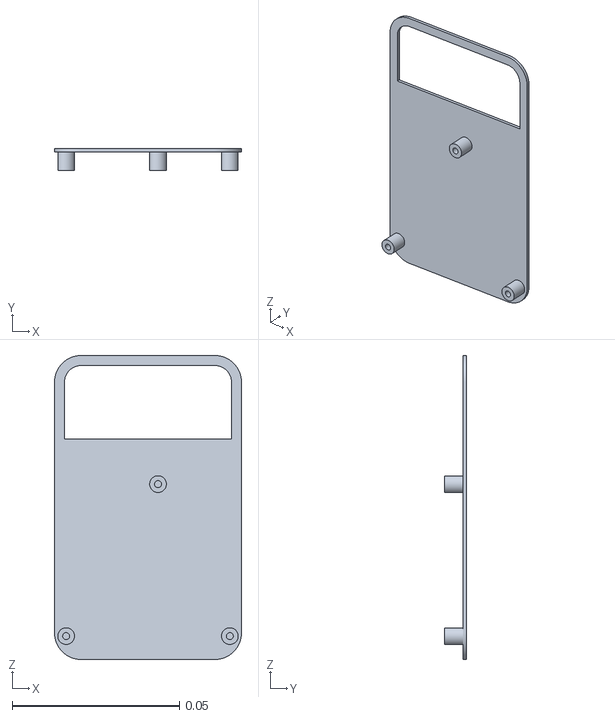
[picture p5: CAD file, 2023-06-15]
stls/PCBMount.stl
0.056 x 0.0065 x 0.091

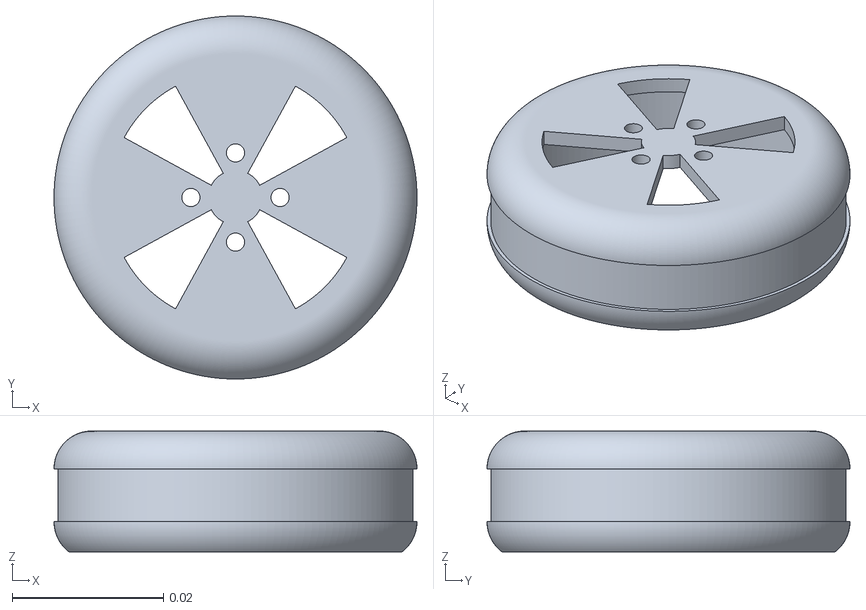
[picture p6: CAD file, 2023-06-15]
stls/Wheel.stl
0.048 x 0.048 x 0.016

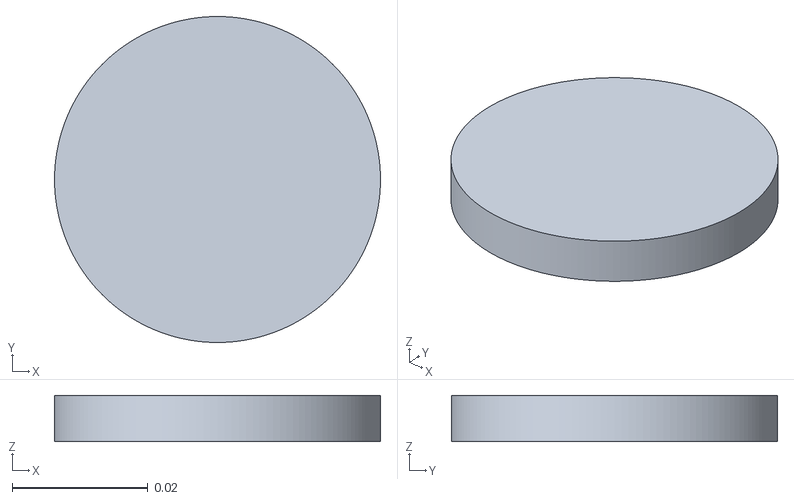
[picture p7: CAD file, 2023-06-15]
stls/Tire.stl
0.048 x 0.048 x 0.0068

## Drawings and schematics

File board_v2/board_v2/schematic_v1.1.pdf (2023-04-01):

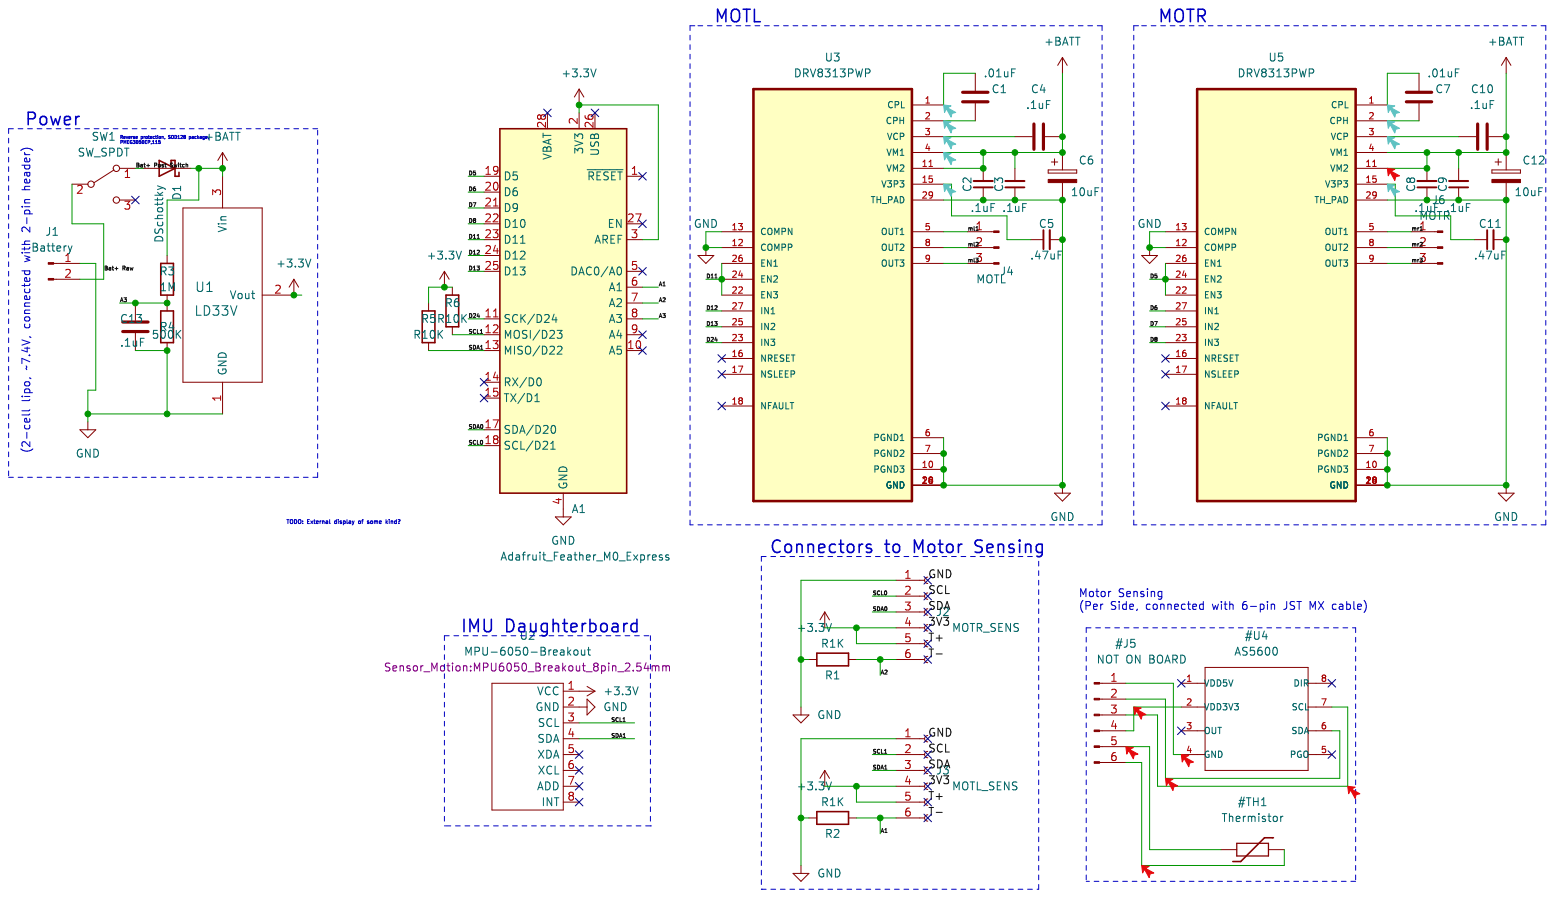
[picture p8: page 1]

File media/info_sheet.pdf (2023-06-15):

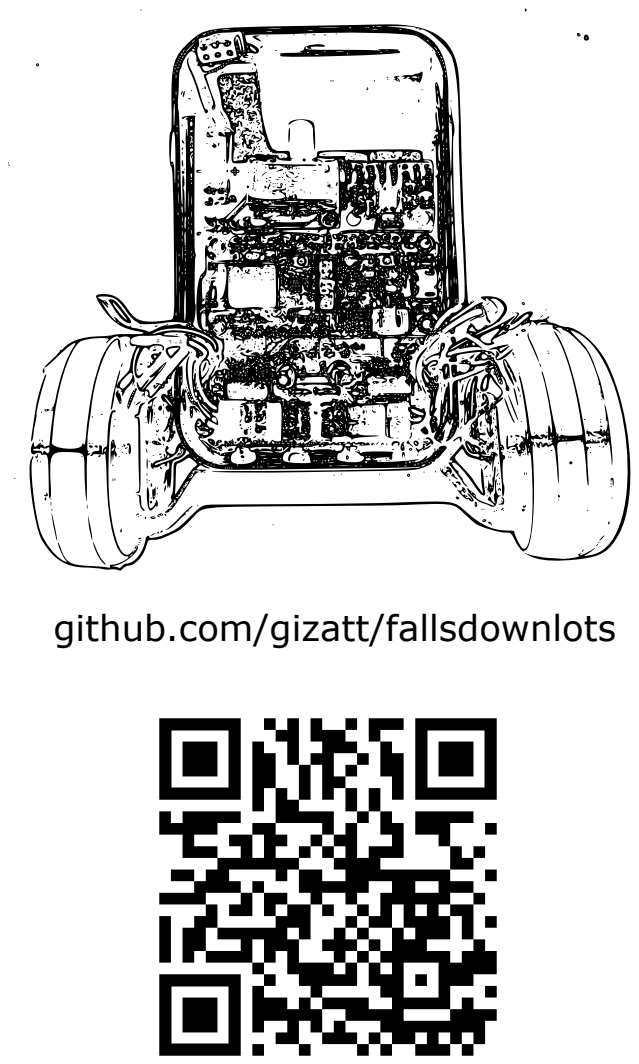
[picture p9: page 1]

github.com/gizatt/fallsdownlots

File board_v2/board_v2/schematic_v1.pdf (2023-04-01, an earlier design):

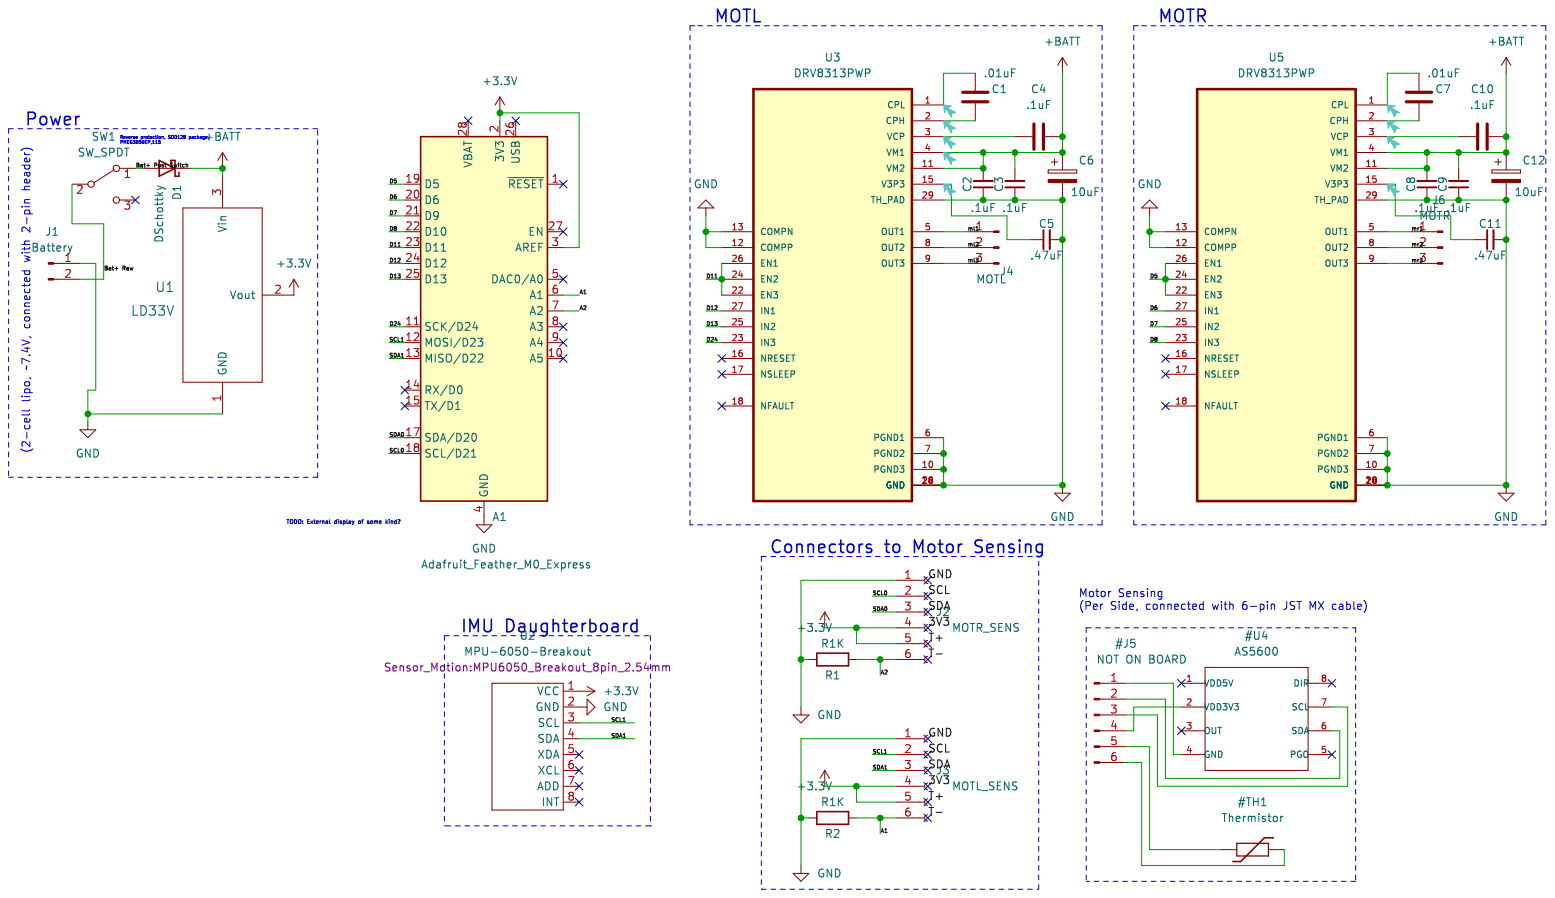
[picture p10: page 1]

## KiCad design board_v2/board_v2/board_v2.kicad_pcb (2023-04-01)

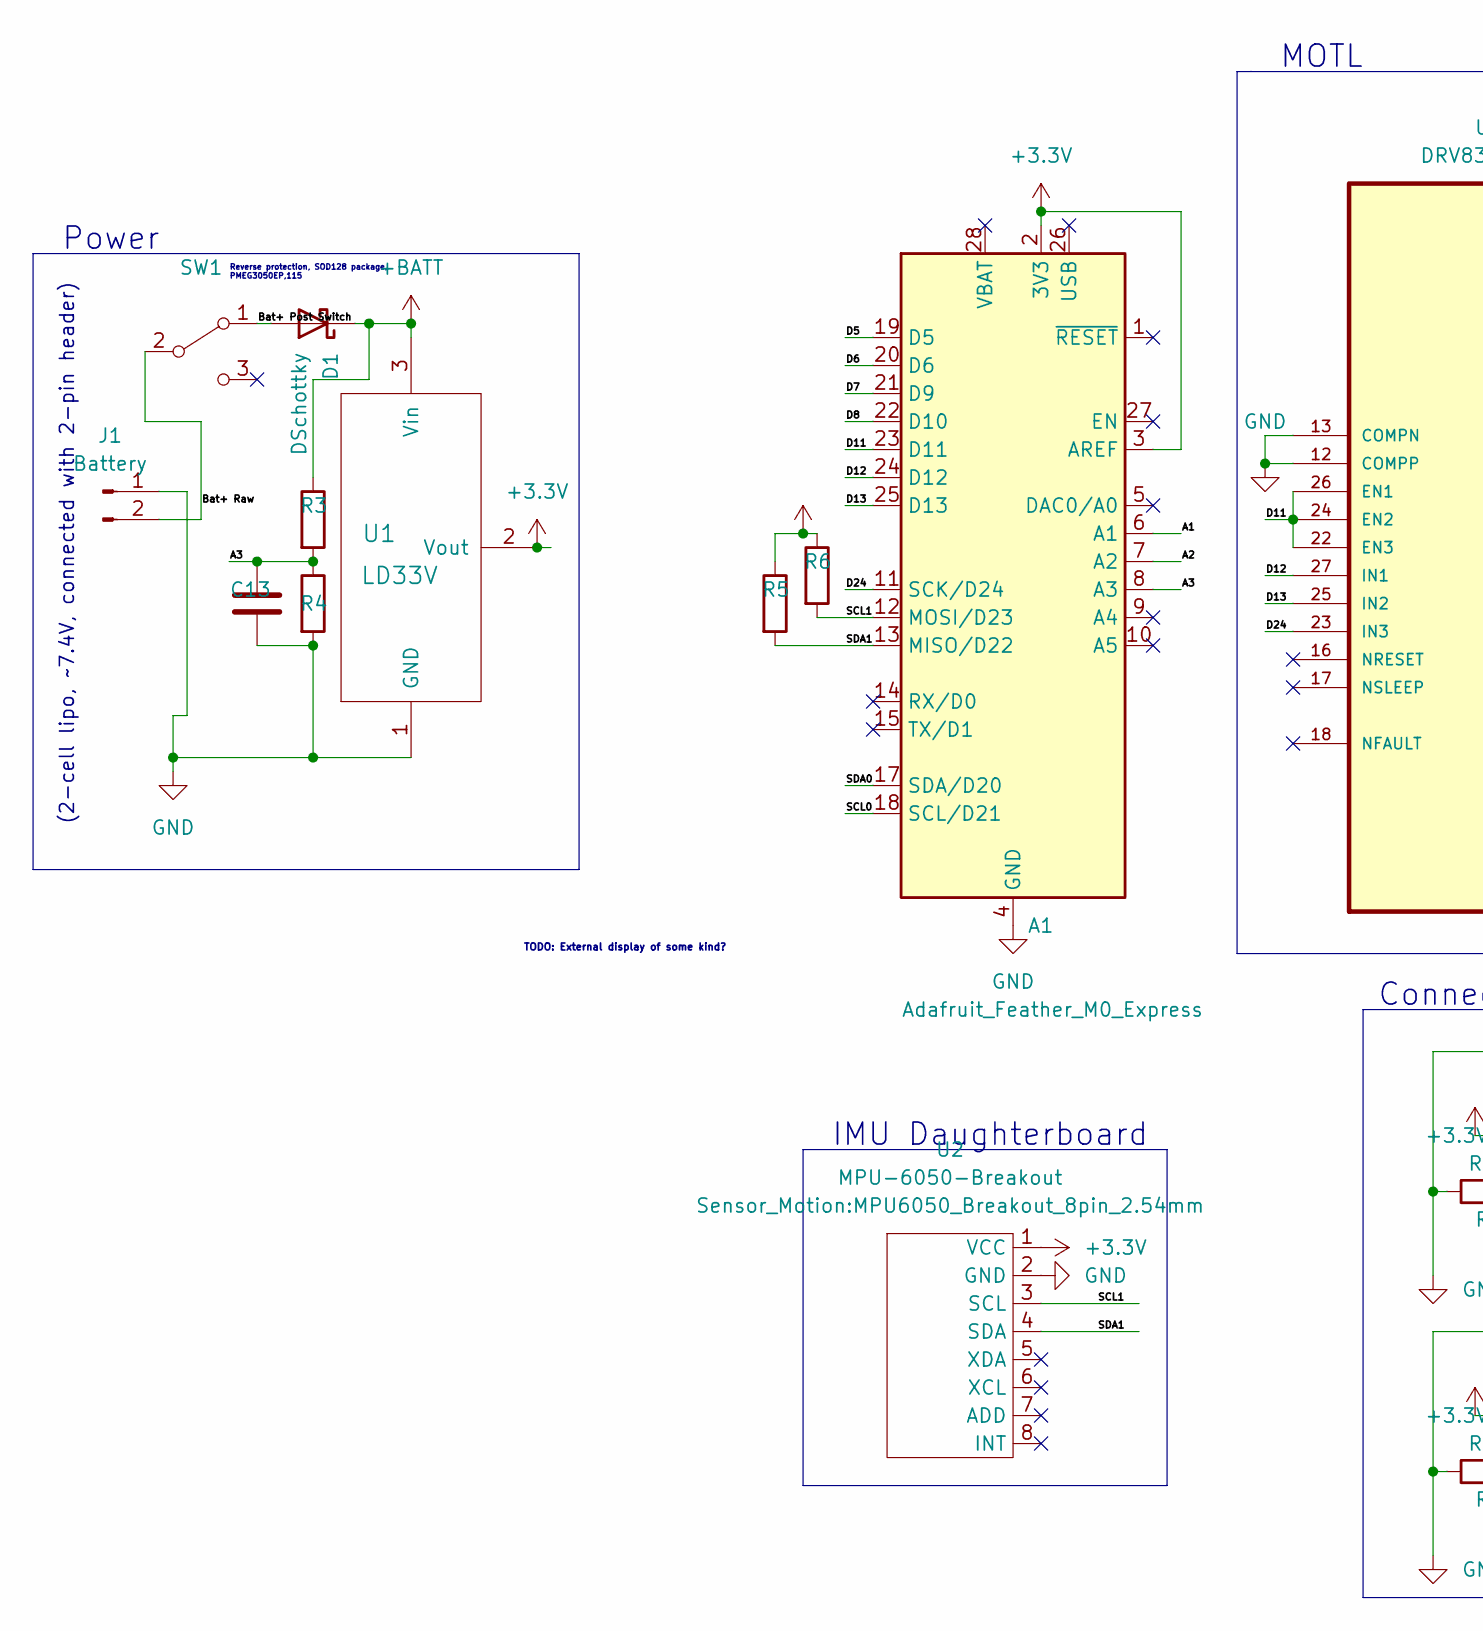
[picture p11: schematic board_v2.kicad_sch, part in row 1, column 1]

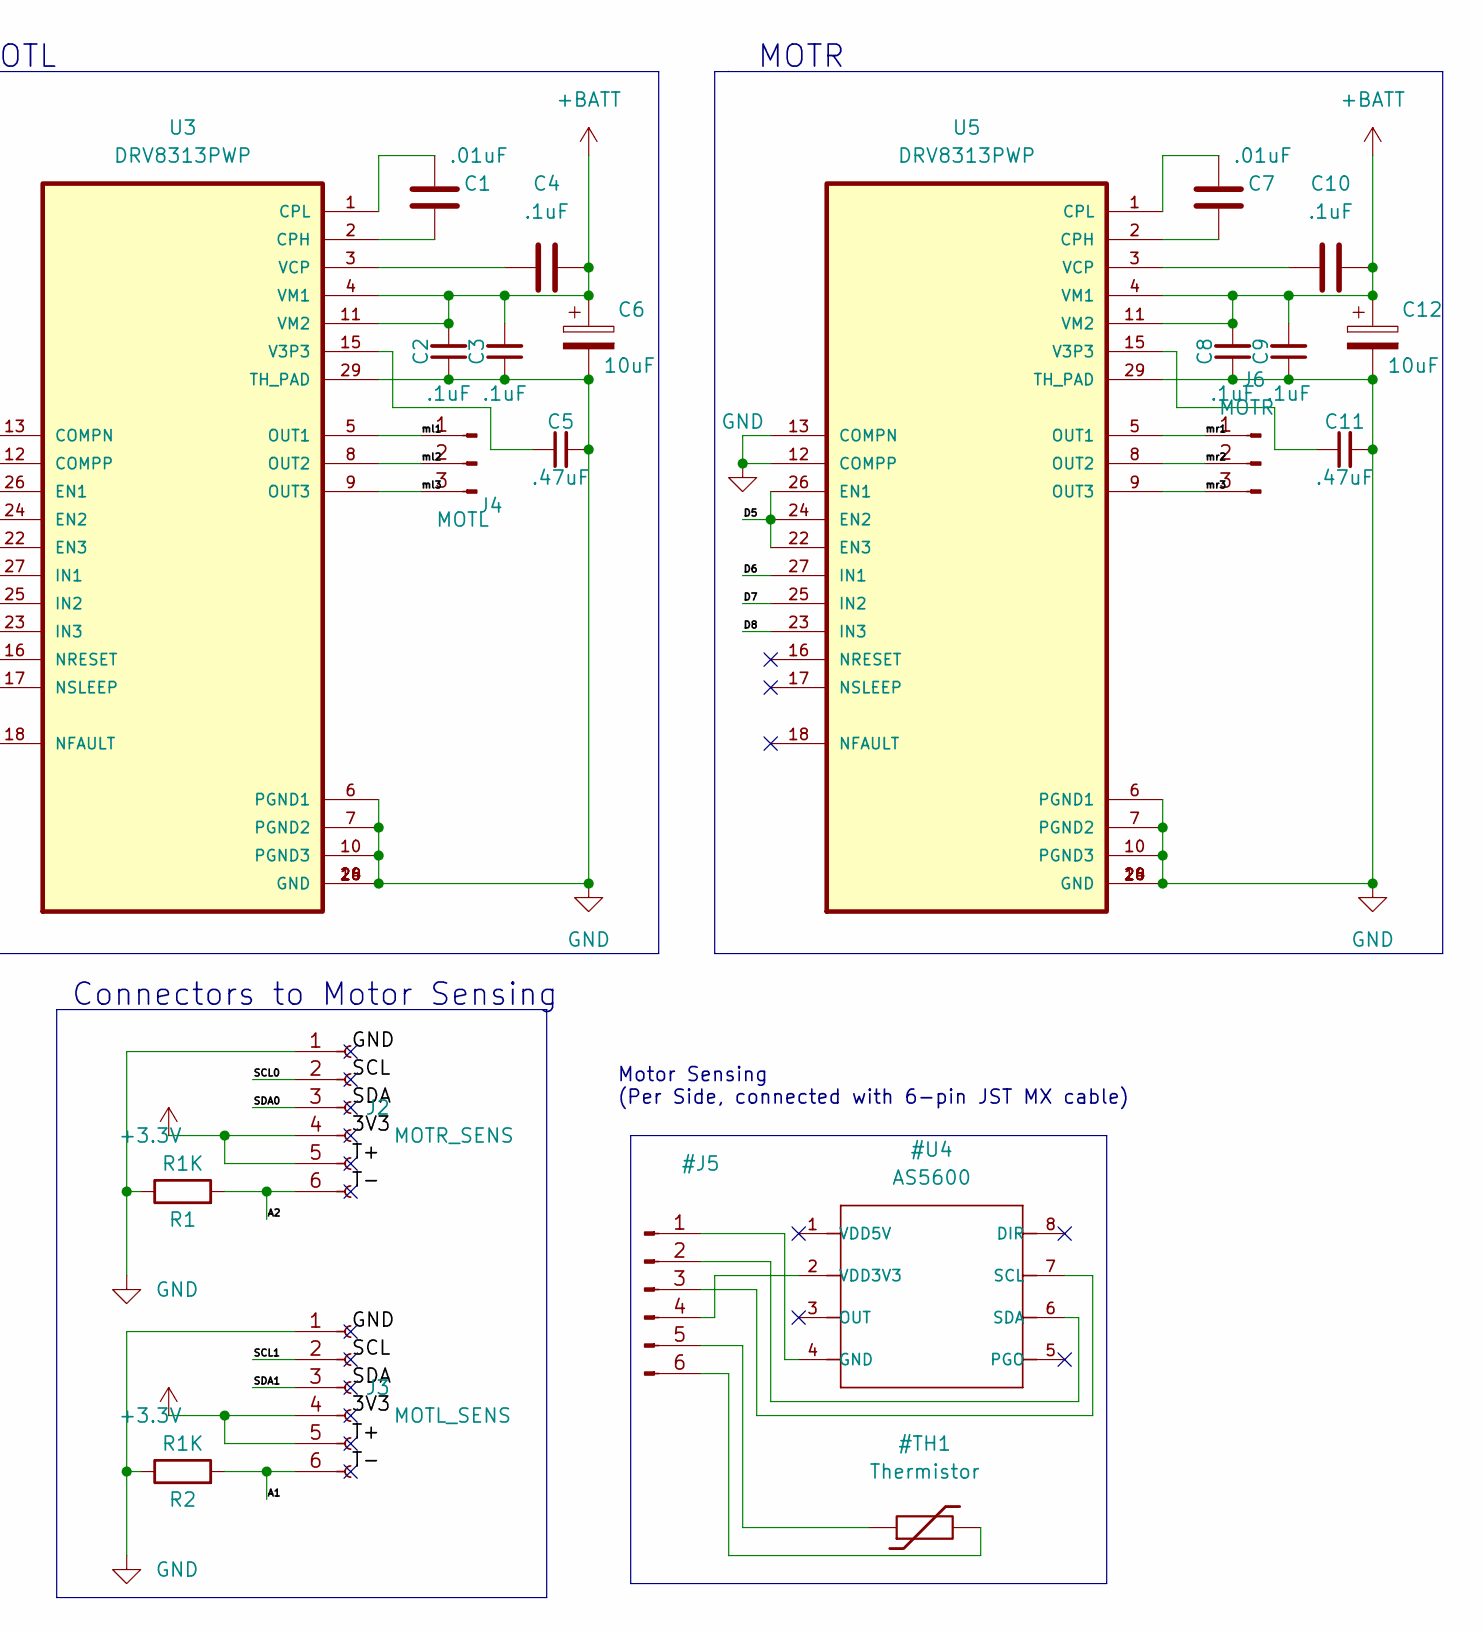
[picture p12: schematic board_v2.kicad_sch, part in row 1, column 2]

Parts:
A1: Adafruit_Feather_M0_Express; Adafruit_Feather_M0_Wifi_WithMountingHoles
C1, C7: .01uF; C_0805_2012Metric_Pad1.18x1.45mm_HandSolder
C2, C3, C4, C8, C9, C10: .1uF; C_0805_2012Metric_Pad1.18x1.45mm_HandSolder
C5, C11: .47uF; C_0805_2012Metric_Pad1.18x1.45mm_HandSolder
C6, C12: 10uF; CP_Radial_D5.0mm_P2.50mm
C13: (no value)
D1: DSchottky; D_SOD-128
J1: Battery; PinHeader_1x02_P2.54mm_Horizontal
J2: MOTR_SENS; JST MX x6
J3: MOTL_SENS; JST MX x6
J4: MOTL; PinHeader_1x03_P2.54mm_Horizontal
J6: MOTR; PinHeader_1x03_P2.54mm_Horizontal
R1, R2: R1K; R_0805_2012Metric_Pad1.20x1.40mm_HandSolder
R3, R4, R5, R6: (no value)
SW1: (no value)
U1: LD33V; TO-220-3_Horizontal_TabDown
U2: MPU-6050-Breakout; MPU6050_Breakout_8pin_2.54mm
U3, U5: DRV8313PWP; IC_TPS61196PWPRQ1

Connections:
+BATT: C2.2, C3.2, C4.2, C6.1, C8.2, C9.2, C10.2, C12.1, D1.1 (K), R3.1, U1.3 (Vin), U3.4 (VM1), U3.11 (VM2), U5.4 (VM1), U5.11 (VM2)
/A1: A1.6 (A1), J3.6, R2.2
/A2: A1.7 (A2), J2.6, R1.2
/A3: A1.8 (A3), C13.1, R3.2, R4.1
/Bat+ Post Switch: D1.2 (A), SW1.1 (A)
/Bat+ Raw: J1.2, SW1.2 (B)
/D5: A1.19 (D5), U5.22 (EN3), U5.24 (EN2), U5.26 (EN1)
/D6: A1.20 (D6), U5.27 (IN1)
/D7: A1.21 (D9), U5.25 (IN2)
/D8: A1.22 (D10), U5.23 (IN3)
/D11: A1.23 (D11), U3.22 (EN3), U3.24 (EN2), U3.26 (EN1)
/D12: A1.24 (D12), U3.27 (IN1)
/D13: A1.25 (D13), U3.25 (IN2)
/D24: A1.11 (SCK/D24), U3.23 (IN3)
/SCL0: A1.18 (SCL/D21), J2.2
/SCL1: A1.12 (MOSI/D23), J3.2, R6.2, U2.3 (SCL)
/SDA0: A1.17 (SDA/D20), J2.3
/SDA1: A1.13 (MISO/D22), J3.3, R5.2, U2.4 (SDA)
/ml1: J4.1, U3.5 (OUT1)
/ml2: J4.2, U3.8 (OUT2)
/ml3: J4.3, U3.9 (OUT3)
/mr1: J6.1, U5.5 (OUT1)
/mr2: J6.2, U5.8 (OUT2)
/mr3: J6.3, U5.9 (OUT3)
GND: A1.4 (GND), A1.16 (GND), C2.1, C3.1, C5.2, C6.2, C8.1, C9.1, C11.2, C12.2, C13.2, J1.1, J2.1, J3.1, R1.1, R2.1, R4.2, U1.1 (GND), U2.2 (GND), U3.6 (PGND1), U3.7 (PGND2), U3.10 (PGND3), U3.12 (COMPP), U3.13 (COMPN), U3.14 (GND), U3.20 (GND), U3.28 (GND), U3.29 (TH_PAD), U5.6 (PGND1), U5.7 (PGND2), U5.10 (PGND3), U5.12 (COMPP), U5.13 (COMPN), U5.14 (GND), U5.20 (GND), U5.28 (GND), U5.29 (TH_PAD)
unnamed: C1.1, U3.1 (CPL)
unnamed: C1.2, U3.2 (CPH)
unnamed: C4.1, U3.3 (VCP)
unnamed: C5.1, U3.15 (V3P3)
unnamed: C7.1, U5.1 (CPL)
unnamed: C7.2, U5.2 (CPH)
unnamed: C10.1, U5.3 (VCP)
unnamed: C11.1, U5.15 (V3P3)

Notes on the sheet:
Power
TODO: External display of some kind?
IMU Daughterboard
MOTL
Motor Sensing (Per Side, connected with 6-pin JST MX cable)
MOTR
(2-cell lipo, ~7.4V, connected with 2-pin header)
Connectors to Motor Sensing
Reverse protection, SOD128 package, PMEG3050EP,115

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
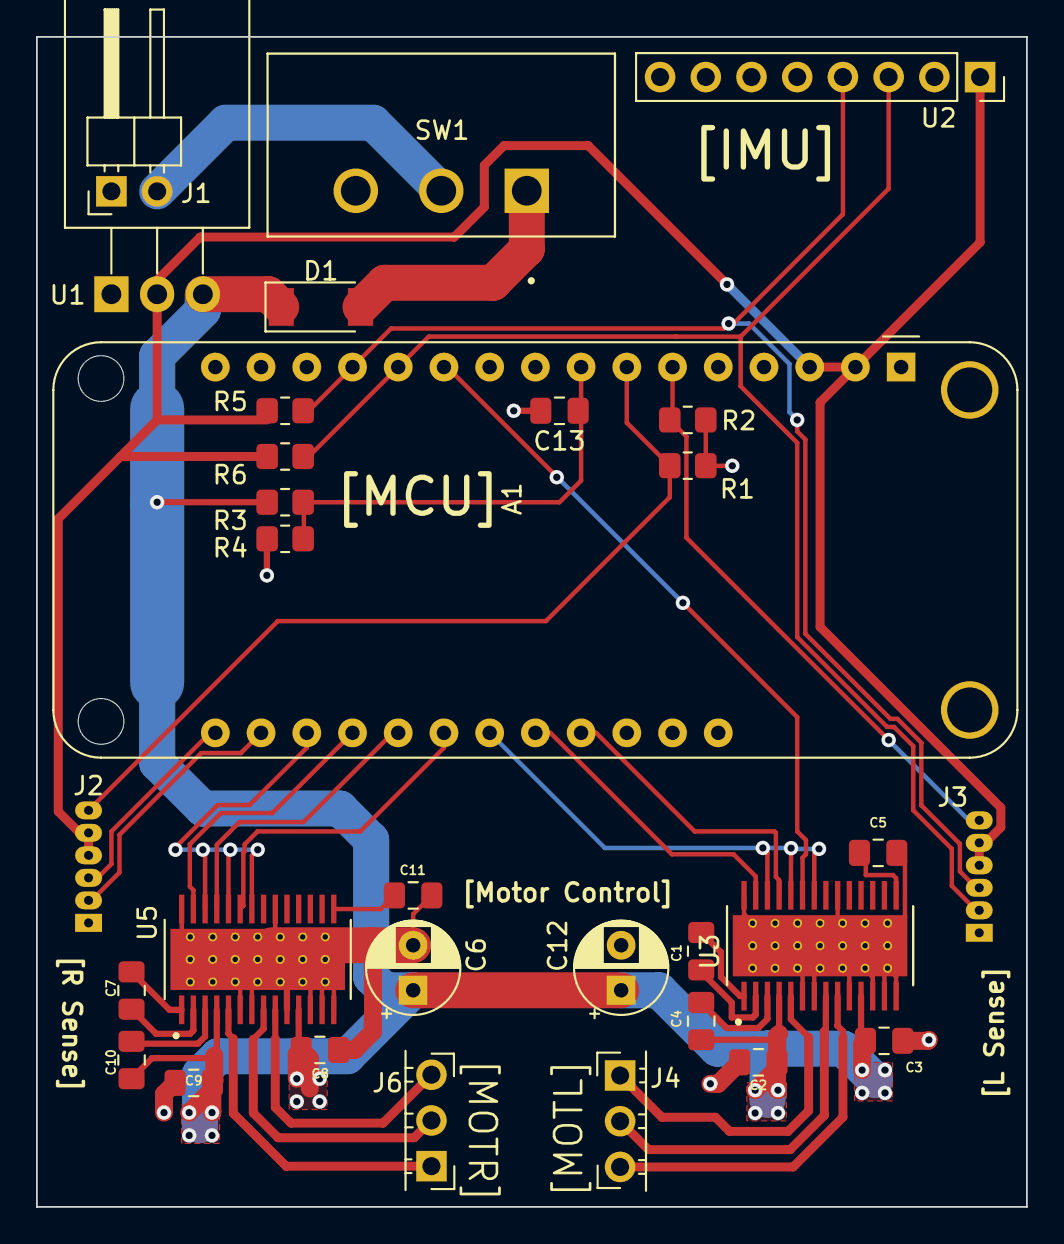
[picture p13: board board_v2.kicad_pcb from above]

Board: 2 copper layers, 55.0 x 65.0 mm, 31 parts (0 on the bottom side), 34 nets.

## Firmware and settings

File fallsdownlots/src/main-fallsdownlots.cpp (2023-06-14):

/**
 * A robot that falls down lots.
 */
#include "SPI.h"
#include <SimpleFOC.h>
#include "IMU.hpp"
#include "BLEManager.hpp"
#include "ThermistorManager.hpp"

MagneticSensorI2C as5600_r = MagneticSensorI2C(AS5600_I2C);
TwoWire &Wire_r = Wire;
BLDCMotor motor_r = BLDCMotor(7, 12.0, 450); // Nominally 250, but this value passes the 0-torque-makes-it-feel-smooth test.
BLDCDriver3PWM driver_r = BLDCDriver3PWM(6, 9, 10, 5);
const int MOTOR_R_THERMISTOR_READ_PIN = A3;
const int MOTOR_R_THERMISTOR_WRITE_PIN = A4;
const float MOTOR_R_THERMISTOR_R_DIVIDER = 1000; // ohms
const float MOTOR_THERMISTOR_LOWPASS_RC = 0.5;

MagneticSensorI2C as5600_l = MagneticSensorI2C(AS5600_I2C);
TwoWire Wire_l(NRF_TWIM1, NRF_TWIS1, SPIM1_SPIS1_TWIM1_TWIS1_SPI1_TWI1_IRQn, 24, 25);
BLDCMotor motor_l = BLDCMotor(7, 12.0, 450); // Nominally 250, but this value passes the 0-torque-makes-it-feel-smooth test.
BLDCDriver3PWM driver_l = BLDCDriver3PWM(12, 13, 26, 11);
const int MOTOR_L_THERMISTOR_READ_PIN = A2;
const int MOTOR_L_THERMISTOR_WRITE_PIN = A1;
const float MOTOR_L_THERMISTOR_R_DIVIDER = 1000; // ohms

const float MAX_TEMP = 70.0; // Celsius, max temp for motors before thermal shutoff disables control.

IMU mpu(Wire_l, &Serial);
ThermistorManager thermistor_l(MOTOR_L_THERMISTOR_READ_PIN, MOTOR_L_THERMISTOR_WRITE_PIN, MOTOR_L_THERMISTOR_R_DIVIDER, MOTOR_THERMISTOR_LOWPASS_RC);
ThermistorManager thermistor_r(MOTOR_R_THERMISTOR_READ_PIN, MOTOR_R_THERMISTOR_WRITE_PIN, MOTOR_R_THERMISTOR_R_DIVIDER, MOTOR_THERMISTOR_LOWPASS_RC);

// Control params.
struct NamedControlParam {
  // Actual value of the param.
  float value;
  // String name by which this param will be referred in the serial protocol. Keep this short.
  const char * name;
};

struct ControlParams {
  NamedControlParam angle_p = {1.0, "ANG_P"};
  NamedControlParam angle_d = {0.06, "ANG_D"};
  NamedControlParam angle_target_rc = {10.0, "ANG_RC"};
  NamedControlParam angle_error_max = {1.0, "ANG_TM"};
  NamedControlParam vel_p = {0.02, "VEL_P"};
  NamedControlParam vel_target = {0.0, "VEL_T"};
  NamedControlParam vel_i = {0.01, "VEL_I"};
  NamedControlParam vel_i_max = {10.0, "VEL_IM"}; // More than enough. Probably getting a little windup here.
  NamedControlParam dyaw_p = {0.05, "DYAW_P"};
  NamedControlParam dyaw_target = {0.00, "DYAW_T"};
  NamedControlParam dyaw_i = {0.00, "DYAW_I"};
  NamedControlParam dyaw_i_max = {1.0, "DYAW_IM"};
  NamedControlParam target_decay_rc = {1.0, "DEC_RC"};
  NamedControlParam target_decay_timeout = {1.0, "DEC_TM"};
  NamedControlParam send_state = {0.0, "SEND_STATE"}; // Must set to >= 0.5 to enable sending state messages.
} control_params;

// Error integrator state
float integrated_velocity_error = 0.0;
float integrated_dyaw_error = 0.0;
float average_angle = 0.0;


uint8_t send_buf[256];
uint32_t last_received_ble_packet_millis;
void onBLEPacketReceived(const uint8_t *buffer, size_t size)
{
  // Get as many chars off the front that are valid ascii chars to get a name.
  size_t name_len = 0;
  for (name_len = 0; name_len < size && buffer[name_len] >= 32 && buffer[name_len] <= 127 ;  name_len++) { ; }
  if (name_len == 0) {
    Serial.printf("Couldn't parse packet, bad name len %u\n", name_len);
    return;
  }
  int val_len = size - name_len - 1;
  if (val_len != 0 && val_len != 4){
    Serial.printf("Got invalid val len in packet: %u\n", val_len);
    return;
  }
  // Check the name against our parameters and see if any match.
  bool found_matching_param = false;
  for (uint8_t param_k = 0; param_k < (sizeof(control_params) / sizeof(NamedControlParam)); param_k++){
    // Hacky technique for iterating over our named control params...
    auto * control_param = (NamedControlParam *)(&control_params) + param_k;
    if (strncmp(control_param->name, (const char *)buffer, name_len) == 0){
      found_matching_param = true;
      if (val_len == 4){
        // Update param.
        control_param->value = * (float *) (buffer + name_len + 1);
      }

      memcpy(send_buf, buffer, name_len + 1);
      memcpy(send_buf + name_len + 1, &(control_param->value), sizeof(float));
      maybe_send_ble_uart(send_buf, name_len + 1 + sizeof(float));
      last_received_ble_packet_millis = millis();
      break;
    }
  }
  if (!found_matching_param){
    Serial.printf("Couldn't find param with name %.*s to update\n", name_len, buffer);
  }
}

void setup()
{
  analogReadResolution(12);

  // monitoring port
  Serial.begin(115200);

  Wire_l.setClock(TWIM_FREQUENCY_FREQUENCY_K400);
  Wire_r.setClock(TWIM_FREQUENCY_FREQUENCY_K400);
  Wire_l.begin();
  Wire_r.begin();

  // Talk to IMU
  while (!mpu.try_connect())
  {
    Serial.println("Failed to find MPU6050 chip");
    delay(1000);
  }
  Serial.println("MPU6050 Found!");

  while (!begin_ble("fallsdownlots"))
  {
    Serial.println("Failed to set up BLE.");
    delay(1000);
  }
  blueart_packet_serial.setPacketHandler(&onBLEPacketReceived);
  last_received_ble_packet_millis = millis();

  // Initialize magnetic encoders.
  as5600_r.init(&Wire_r);
  as5600_l.init(&Wire_l);

  Serial.println("AS5600 ready");
  _delay(100);

  // initialize motor
  // driver config
  // power supply voltage [V]
  driver_r.voltage_power_supply = 7.4;
  driver_r.init();
  motor_r.linkDriver(&driver_r);
  motor_r.linkSensor(&as5600_r);

  // set control loop type to be used
  motor_r.torque_controller = TorqueControlType::voltage;
  motor_r.PID_velocity.output_ramp = 1000;
  motor_r.controller = MotionControlType::torque;
  // limiting voltage
  motor_r.voltage_limit = 7.4; // Volts
  // or current  - if phase resistance provided
  motor_r.current_limit = 1.0; // Amps
  motor_r.PID_velocity.P = 0.1;
  motor_r.PID_velocity.D = 0.001;
  motor_r.PID_velocity.I = 10;
  motor_r.LPF_velocity.Tf = 0.1;

  // initialise motor
  motor_r.useMonitoring(Serial);
  motor_r.init();
  // align encoder and start FOC
  motor_r.initFOC();
  // set the inital target value
  motor_r.target = 0;
  motor_r.velocity_limit = 1000;
  Serial.println("Motor R ready");

  // initialize motor
  // driver config
  // power supply voltage [V]
  driver_l.voltage_power_supply = 7.4;
  driver_l.init();
  motor_l.linkDriver(&driver_l);
  motor_l.linkSensor(&as5600_l);

  // set control loop type to be used
  motor_l.torque_controller = TorqueControlType::voltage;
  motor_l.PID_velocity.output_ramp = 1000;
  motor_l.controller = MotionControlType::torque;
  // limiting voltage
  motor_l.voltage_limit = 7.4; // Volts
  // or current  - if phase resistance provided
  motor_l.current_limit = 1.0; // Amps
  motor_l.PID_velocity.P = 0.1;
  motor_l.PID_velocity.D = 0.001;
  motor_l.PID_velocity.I = 10;
  motor_l.LPF_velocity.Tf = 0.1;

  // initialise motor
  motor_l.useMonitoring(Serial);
  motor_l.init();
  // align encoder and start FOC
  motor_l.initFOC();
  // set the inital target value
  motor_l.target = 0;
  motor_l.velocity_limit = 1000;
  Serial.println("Motor L ready");
}

float clamp(float x, float lb, float ub){
  return min(max(x, lb), ub);
}

float average_velocity(){
 return 0.5 * motor_l.shaftVelocity() + 0.5 * motor_r.shaftVelocity();
}

uint32_t last_control_update_t = 0;
void do_control()
{
  uint32_t t = micros();
  float dt = ((float)(t - last_control_update_t)) / 1E6;
  last_control_update_t = t;

  if (millis() - last_received_ble_packet_millis >= control_params.target_decay_timeout.value * 1000){
    // Decay our "target" inputs back to zero if they're older than our timeout value
    float target_decay_alpha = 1. - dt / (control_params.target_decay_rc.value + dt);
    control_params.vel_target.value *= target_decay_alpha;
    control_params.dyaw_target.value *= target_decay_alpha;
  }

  float target_torque_l = 0.0;
  float target_torque_r = 0.0;
  if (fabs(mpu.pitch()) < control_params.angle_error_max.value && thermistor_l.get_temperature() <= MAX_TEMP && thermistor_r.get_temperature() <= MAX_TEMP)
  {  
    // Update estimated "upright" angle by averaging our angle measurements.
    float alpha = 1.0 - dt / (control_params.angle_target_rc.value + dt);
    average_angle = average_angle * alpha + (1.0 - alpha) * mpu.pitch();

    float pitch_error = mpu.pitch() - average_angle;
    float velocity_error = average_velocity() - control_params.vel_target.value;
    integrated_velocity_error += dt * velocity_error;
    integrated_velocity_error = clamp(integrated_velocity_error, -control_params.vel_i_max.value, control_params.vel_i_max.value);

    float dyaw_error = mpu.dyaw() - control_params.dyaw_target.value;
    integrated_dyaw_error += dt * dyaw_error;
    integrated_dyaw_error = clamp(integrated_dyaw_error, -control_params.dyaw_i_max.value, control_params.dyaw_i_max.value);
    
    float pitch_component = control_params.angle_p.value * pitch_error + control_params.angle_d.value * mpu.dpitch();
    float odometry_component = control_params.vel_p.value * velocity_error + control_params.vel_i.value * integrated_velocity_error;
    float dyaw_component = control_params.dyaw_p.value * dyaw_error + control_params.dyaw_i.value * integrated_dyaw_error;
    target_torque_l = pitch_component + odometry_component - dyaw_component;
    target_torque_r = pitch_component + odometry_component + dyaw_component;
  } else {
    integrated_velocity_error = 0.0;
    integrated_dyaw_error = 0.0;
    average_angle = 0.0;
  }

  motor_l.move(target_torque_l);
  motor_r.move(target_torque_r);
}

float low_pass_x_acc = 0.;

long unsigned int last_printed_status_t = 0;
long unsigned int last_sent_state_est_t = 0;
long unsigned int last_command_t = 0;
long unsigned int last_thermistor_read_t = 0;
long unsigned int last_ble_uart_update = 0;

float ble_state_send_buffer[12]; // Will be populated with pitch, dpitch, dyaw, integrated_velocity_error, integrated_yaw_error, control_l, angle_l, vel_l, control_r, angle_r, vel_r, max_motor_temp
void loop()
{
  long unsigned int t = millis();

  // Loop management to prioritize good state estimation (targeting 1khz)
  // We're very limited by I2C comm rate, which is set to its max (400khz).
  mpu.update();

  if (t - last_command_t > 1)
  {
    last_command_t = t;
    // TODO(gizatt) I'm pretty sure the source of slowness here is I2C comms
    // with both magnetic sensors. I suspect it'd be pretty straightforward
    // to make a new MagneticSensorI2C class that reads the sensor at a slow
    // rate (like 30hz), estimates velocity from the signals, and returns
    // projected rotation estimates at higher rates.
    as5600_r.update();
    as5600_l.update();
    motor_l.loopFOC();
    motor_r.loopFOC();
    do_control();
  }

  if (t - last_thermistor_read_t > 50)
  {
    last_thermistor_read_t = t;
    // Don't need tons of accuracy out of these, so don't update super frequently.
    thermistor_l.update();
    thermistor_r.update();
  }

  if (t - last_ble_uart_update > 1)
  {
    last_ble_uart_update = t;
    update_ble_uart();
  }

  if (t - last_sent_state_est_t > 50 && control_params.send_state.value >= 0.5)
  {
    last_sent_state_est_t = t;
    // display the angle and the angular velocity to the terminal
    float l_temp = thermistor_l.get_temperature();
    float r_temp = thermistor_r.get_temperature();

    // Send current state as a simple float buffer
    ble_state_send_buffer[0] = mpu.pitch();
    ble_state_send_buffer[1] = mpu.dpitch();
    ble_state_send_buffer[2] = mpu.dyaw();
    ble_state_send_buffer[3] = integrated_velocity_error;
    ble_state_send_buffer[4] = integrated_dyaw_error;
    ble_state_send_buffer[5] = motor_l.target;
    ble_state_send_buffer[6] = as5600_l.getAngle();
    ble_state_send_buffer[7] = motor_l.shaftVelocity();
    ble_state_send_buffer[8] = motor_r.target;
    ble_state_send_buffer[9] = as5600_r.getAngle();
    ble_state_send_buffer[10] = motor_r.shaftVelocity();
    ble_state_send_buffer[11] = max(l_temp, r_temp);
    maybe_send_ble_uart((uint8_t *)ble_state_send_buffer, sizeof(float) * 12);
  }

  if (t - last_printed_status_t > 250)
  {
    // Display detailed stats to the terminal.
    last_printed_status_t = t;
    float l_temp = thermistor_l.get_temperature();
    float r_temp = thermistor_r.get_temperature();

    Serial.printf("L[%04.2fr %04.2frs %04.2ft %04.2fC] R[%04.2fr %04.2frs  %04.2ft %04.2fC] Int[%04.2f %04.2f] IMU[%04.2f %04.2f %04.2fms avg, %04.2fms worst]\n",
      as5600_l.getAngle(), motor_l.shaftVelocity(), motor_l.target, l_temp,
      as5600_r.getAngle(), motor_r.shaftVelocity(), motor_r.target, r_temp,
      integrated_velocity_error, integrated_dyaw_error,
      mpu.pitch(), mpu.dpitch(), 1000. * mpu.avg_update_dt(), 1000. * mpu.worst_update_dt());
    mpu.reset_worst_update_dt();
  }
  
}

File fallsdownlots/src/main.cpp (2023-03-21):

/**
 * Robot that falls down lots
 */

// We need both I2C devices.
#include "snprinth.h"

#include "Arduino.h"

#include "LEDBlinker.hpp"
#include "IMU.hpp"
#include "Display.hpp"
#include "Motor.hpp"

#ifndef LED_BUILTIN
#define LED_BUILTIN 13
#endif

LEDBlinker *blinker;
IMU *imu;
Display *display;

StepperMotor *motor;
const uint8_t EN_A = 7;
const uint8_t FWD_A = 6; // PWM
const uint8_t REV_A = 9; // PWM
const uint8_t EN_B = 8;
const uint8_t FWD_B = 10; // PWM
const uint8_t REV_B = 16; // PWM

const uint8_t POT_PIN = 14;

void setup()
{
  Serial.begin(115200); // actually starts at some crazy USB rate

  pinMode(POT_PIN, INPUT);

  display = new Display();
  blinker = new LEDBlinker(LED_BUILTIN);
  imu = new IMU();
  motor = new StepperMotor(EN_A, FWD_A, REV_A, EN_B, FWD_B, REV_B);
}

uint32_t last_update_t = 0;
uint32_t last_update_t_us = 0;
uint32_t last_publish_t_us = 0;
char print_buf[256];

// State
float pos_est = 0.;
float speed_est = 0.;
float speed_est_slow = 0.;
float ang_est = 0.;
float dang_est = 0.;
float ang_target = 2.5;
float SPEED_EST_BW = 0.05;
float SPEED_EST_SLOW_BW = 0.25;

// Feedback gains
float K_pos = -0.1;
float K_speed = -2.;
float K_ang = 0.2;
float K_dang = 0.0;

// To activate: put very close to balanced for
// a few seconds.
bool active = false;
uint32_t active_start_timer = 0;

void loop()
{
  auto t = millis();

  // Update all modules.
  blinker->update(t);
  imu->update(t);
  display->update(t);
  motor->update(t);

  // Positive angle is corrected by positive speed.

  ang_est = imu->angle() * 180. / PI;
  dang_est = imu->dangle() * 180. / PI;

  float speed_set = 0.;

  // Decide to turn on if we're in the "good" region for long enough.
  if (!active && abs(ang_est - ang_target) <= 5.)
  {
    if (t - active_start_timer > 1000)
    {
      active = true;
    }
  }
  else
  {
    active_start_timer = t;
  }

  if (active && abs(ang_est - ang_target) <= 15.)
  {
    float pos_err = (0. - pos_est);
    // clamp pos error contribution to control.
    pos_err = min(max(pos_err, -1.), 1.);
    speed_set = (ang_target - ang_est) * K_ang + (0. - K_dang) * K_dang + pos_err * K_pos + (0. - speed_est_slow) * K_speed;
  }
  else
  {
    active = false;
    speed_set = 0.;
    pos_est = 0.;
    speed_est = 0.;
    speed_est_slow = 0.;
  }
  speed_set = min(max(speed_set, -1.), 1.);
  motor->set_speed(speed_set);

  // Step odometry
  auto t_us = micros();
  uint32_t dt = t_us - last_update_t_us;
  if (dt >= 100)
  {
    last_update_t_us = t_us;
    float dt_f = ((float)dt) / 1E6;

    // run smooth and less smooth speed estimators for control and odometry respectively
    float speed_est_alpha = 1. - dt_f / (SPEED_EST_BW + dt_f);
    float speed_est_slow_alpha = 1. - dt_f / (SPEED_EST_SLOW_BW + dt_f);
    speed_est = speed_est * speed_est_alpha + (1. - speed_est_alpha) * speed_set;
    speed_est_slow = speed_est_slow * speed_est_slow_alpha + (1. - speed_est_slow_alpha) * speed_set;
    pos_est += speed_est * dt_f;
  }
  if (t - last_update_t > 100)
  {
    display->draw_text("x%7.02f dx%7.02f\na%7.02f da%7.02f\nActive: %d", pos_est, speed_est, ang_est, dang_est, active);
    last_update_t = t;
  }

  // Publish
  /*
  if (t_us - last_publish_t_us > 1000)
  {
    last_publish_t_us = t_us;
    snprintf(print_buf, 256, "%0.3f, %0.3f, %0.3f, %0.3f, %0.3f, %0.3f", ((float)t_us) / 1E6, pos_est, speed_est_slow, ang_est, dang_est, speed_set);
    Serial.print(print_buf);
  }
  */
}

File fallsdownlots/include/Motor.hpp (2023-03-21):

#pragma once

#include "Arduino.h"

// Phase chart

/*
const uint32_t N_PHASES = 4;
const uint8_t stepper_phase_chart[16] = {
    1, 0, 1, 0,
    0, 1, 1, 0,
    0, 1, 0, 1,
    1, 0, 0, 1};
*/
const uint32_t PWM_PERIOD_US = 1000;
/*
const uint32_t N_PHASES = 16;
// clang-format off
const uint32_t stepper_phase_chart[N_PHASES * 4] = {
        PWM_PERIOD_US*1.00, PWM_PERIOD_US*0.00, PWM_PERIOD_US*0.50, PWM_PERIOD_US*0.50,
        PWM_PERIOD_US*0.96, PWM_PERIOD_US*0.04, PWM_PERIOD_US*0.69, PWM_PERIOD_US*0.31,
        PWM_PERIOD_US*0.85, PWM_PERIOD_US*0.15, PWM_PERIOD_US*0.85, PWM_PERIOD_US*0.15,
        PWM_PERIOD_US*0.69, PWM_PERIOD_US*0.31, PWM_PERIOD_US*0.96, PWM_PERIOD_US*0.04,
        PWM_PERIOD_US*0.50, PWM_PERIOD_US*0.50, PWM_PERIOD_US*1.00, PWM_PERIOD_US*0.00,
        PWM_PERIOD_US*0.31, PWM_PERIOD_US*0.69, PWM_PERIOD_US*0.96, PWM_PERIOD_US*0.04,
        PWM_PERIOD_US*0.15, PWM_PERIOD_US*0.85, PWM_PERIOD_US*0.85, PWM_PERIOD_US*0.15,
        PWM_PERIOD_US*0.04, PWM_PERIOD_US*0.96, PWM_PERIOD_US*0.69, PWM_PERIOD_US*0.31,
        PWM_PERIOD_US*0.00, PWM_PERIOD_US*1.00, PWM_PERIOD_US*0.50, PWM_PERIOD_US*0.50,
        PWM_PERIOD_US*0.04, PWM_PERIOD_US*0.96, PWM_PERIOD_US*0.31, PWM_PERIOD_US*0.69,
        PWM_PERIOD_US*0.15, PWM_PERIOD_US*0.85, PWM_PERIOD_US*0.15, PWM_PERIOD_US*0.85,
        PWM_PERIOD_US*0.31, PWM_PERIOD_US*0.69, PWM_PERIOD_US*0.04, PWM_PERIOD_US*0.96,
        PWM_PERIOD_US*0.50, PWM_PERIOD_US*0.50, PWM_PERIOD_US*0.00, PWM_PERIOD_US*1.00,
        PWM_PERIOD_US*0.69, PWM_PERIOD_US*0.31, PWM_PERIOD_US*0.04, PWM_PERIOD_US*0.96,
        PWM_PERIOD_US*0.85, PWM_PERIOD_US*0.15, PWM_PERIOD_US*0.15, PWM_PERIOD_US*0.85,
        PWM_PERIOD_US*0.96, PWM_PERIOD_US*0.04, PWM_PERIOD_US*0.31, PWM_PERIOD_US*0.69,
};
//clang-format on
*/
const uint32_t N_PHASES = 32;
// clang-format off
const uint32_t stepper_phase_chart[N_PHASES * 4] = {
        PWM_PERIOD_US*1.00, PWM_PERIOD_US*0.00, PWM_PERIOD_US*0.50, PWM_PERIOD_US*0.50,
        PWM_PERIOD_US*0.99, PWM_PERIOD_US*0.01, PWM_PERIOD_US*0.60, PWM_PERIOD_US*0.40,
        PWM_PERIOD_US*0.96, PWM_PERIOD_US*0.04, PWM_PERIOD_US*0.69, PWM_PERIOD_US*0.31,
        PWM_PERIOD_US*0.92, PWM_PERIOD_US*0.08, PWM_PERIOD_US*0.78, PWM_PERIOD_US*0.22,
        PWM_PERIOD_US*0.85, PWM_PERIOD_US*0.15, PWM_PERIOD_US*0.85, PWM_PERIOD_US*0.15,
        PWM_PERIOD_US*0.78, PWM_PERIOD_US*0.22, PWM_PERIOD_US*0.92, PWM_PERIOD_US*0.08,
        PWM_PERIOD_US*0.69, PWM_PERIOD_US*0.31, PWM_PERIOD_US*0.96, PWM_PERIOD_US*0.04,
        PWM_PERIOD_US*0.60, PWM_PERIOD_US*0.40, PWM_PERIOD_US*0.99, PWM_PERIOD_US*0.01,
        PWM_PERIOD_US*0.50, PWM_PERIOD_US*0.50, PWM_PERIOD_US*1.00, PWM_PERIOD_US*0.00,
        PWM_PERIOD_US*0.40, PWM_PERIOD_US*0.60, PWM_PERIOD_US*0.99, PWM_PERIOD_US*0.01,
        PWM_PERIOD_US*0.31, PWM_PERIOD_US*0.69, PWM_PERIOD_US*0.96, PWM_PERIOD_US*0.04,
        PWM_PERIOD_US*0.22, PWM_PERIOD_US*0.78, PWM_PERIOD_US*0.92, PWM_PERIOD_US*0.08,
        PWM_PERIOD_US*0.15, PWM_PERIOD_US*0.85, PWM_PERIOD_US*0.85, PWM_PERIOD_US*0.15,
        PWM_PERIOD_US*0.08, PWM_PERIOD_US*0.92, PWM_PERIOD_US*0.78, PWM_PERIOD_US*0.22,
        PWM_PERIOD_US*0.04, PWM_PERIOD_US*0.96, PWM_PERIOD_US*0.69, PWM_PERIOD_US*0.31,
        PWM_PERIOD_US*0.01, PWM_PERIOD_US*0.99, PWM_PERIOD_US*0.60, PWM_PERIOD_US*0.40,
        PWM_PERIOD_US*0.00, PWM_PERIOD_US*1.00, PWM_PERIOD_US*0.50, PWM_PERIOD_US*0.50,
        PWM_PERIOD_US*0.01, PWM_PERIOD_US*0.99, PWM_PERIOD_US*0.40, PWM_PERIOD_US*0.60,
        PWM_PERIOD_US*0.04, PWM_PERIOD_US*0.96, PWM_PERIOD_US*0.31, PWM_PERIOD_US*0.69,
        PWM_PERIOD_US*0.08, PWM_PERIOD_US*0.92, PWM_PERIOD_US*0.22, PWM_PERIOD_US*0.78,
        PWM_PERIOD_US*0.15, PWM_PERIOD_US*0.85, PWM_PERIOD_US*0.15, PWM_PERIOD_US*0.85,
        PWM_PERIOD_US*0.22, PWM_PERIOD_US*0.78, PWM_PERIOD_US*0.08, PWM_PERIOD_US*0.92,
        PWM_PERIOD_US*0.31, PWM_PERIOD_US*0.69, PWM_PERIOD_US*0.04, PWM_PERIOD_US*0.96,
        PWM_PERIOD_US*0.40, PWM_PERIOD_US*0.60, PWM_PERIOD_US*0.01, PWM_PERIOD_US*0.99,
        PWM_PERIOD_US*0.50, PWM_PERIOD_US*0.50, PWM_PERIOD_US*0.00, PWM_PERIOD_US*1.00,
        PWM_PERIOD_US*0.60, PWM_PERIOD_US*0.40, PWM_PERIOD_US*0.01, PWM_PERIOD_US*0.99,
        PWM_PERIOD_US*0.69, PWM_PERIOD_US*0.31, PWM_PERIOD_US*0.04, PWM_PERIOD_US*0.96,
        PWM_PERIOD_US*0.78, PWM_PERIOD_US*0.22, PWM_PERIOD_US*0.08, PWM_PERIOD_US*0.92,
        PWM_PERIOD_US*0.85, PWM_PERIOD_US*0.15, PWM_PERIOD_US*0.15, PWM_PERIOD_US*0.85,
        PWM_PERIOD_US*0.92, PWM_PERIOD_US*0.08, PWM_PERIOD_US*0.22, PWM_PERIOD_US*0.78,
        PWM_PERIOD_US*0.96, PWM_PERIOD_US*0.04, PWM_PERIOD_US*0.31, PWM_PERIOD_US*0.69,
        PWM_PERIOD_US*0.99, PWM_PERIOD_US*0.01, PWM_PERIOD_US*0.40, PWM_PERIOD_US*0.60,
};
// clang-format on

// Timer interrupt stepping for *all* stepper motors.
static IntervalTimer stepper_update_timer;
static bool stepper_update_timer_started;
static const uint32_t stepper_update_timer_period_us = 100;
static volatile int n_stepper_motors;
class StepperMotor;
static StepperMotor *steppers[2];
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

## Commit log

2022-05-02 First iteration; 3d printed body with a tiny gear motor from amazon.
    [axle^falls_assem_v1.STL, axle_roller.sldprt, axle_roller^falls_assem_v1.STL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]
2022-05-03 Stepper motor control!
    Maxes at about 2khz
2022-05-03 Revert "Now it plays happy birthday"
    This reverts commit 46fa420b528191eefaf3d61706d850ea1cae0c28.
    [Motor.hpp]
2022-05-03 IMU drives motor
2022-05-06 Schematic update to stepper
    [board.kicad_sch]
2022-05-06 V2 body
    [Body1.sldprt, Body2.STL, Body2.sldprt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]
2022-05-06 Prototype speed ramping... doesnt seem to help much.
2022-05-06 Revert "Prototype speed ramping... doesnt seem to help much."
    This reverts commit a9c41792ba803ab4711aafc375a5761d031a6a4b.
    [Motor.hpp]
2022-05-21 Better logging and IMU filtering, but not good enough.
2022-05-21 Try SimpleFOC stepper driver. Doesn't work well at high speeds... badly configured?
    [main.cpp]
2022-05-21 Revert "Try SimpleFOC stepper driver."
    This reverts commit eb4803a5b4304382071dabc3fbd5138f6ade1855.
    [main.cpp]
2022-05-22 Janky hand-written PWM for smoother motor
2022-05-23 Current config
2022-05-25 Configuration that works! Swapping battery for a 7V lipo was critical
    [Display.hpp, IMU.hpp, main.cpp]
2023-03-21 checkin before swap off of due
    [Motor.hpp, main-angle_sensor.cpp, main-motor_test_stand.cpp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]
2023-04-01 Check in state before computer move
    [Body1.sldprt, Body2.STL, Body2.sldprt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]
2023-05-25 Update V2 board schematics
    [board_v2-B_Cu.gbr, board_v2-B_Mask.gbr, board_v2-B_Paste.gbr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]
2023-05-29 Break out thremistor code to its own class and fix it up.
    [ThermistorManager.hpp, main-fallsdownlots.cpp]
2023-06-04 Fix remaining bugs in param-seting protocol
    [main-fallsdownlots.cpp]
2023-06-05 BOM re-export
    [board_v2_bom.csv]
2023-06-05 IMU changes, yaw control
2023-06-15 Big cleanup
    [Body1.sldprt, Body2.STL, Body2.sldprt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]
2023-06-15 Add sheet to print
